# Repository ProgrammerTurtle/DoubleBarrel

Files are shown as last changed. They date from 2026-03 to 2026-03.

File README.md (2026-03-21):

# DoubleBarrel HotEnd

DoubleBarrel is a **high-flow**, **ultra-long-meltzone** 3D printer hotend for my **high performance** custom builds, mainly [Quantumania](https://github.com/ProgrammerTurtle/Quantumania).

With an 80mm meltzone and dual 80mm long mains heater cartridges, totaling a whopping 240 watts, this is a hotend that will heat up in no time and maintain higher flow than *almost* any existing extruder can handle. **Almost**. 

doublebarrelhotendmain

This hot end was designed for HackClub Rework.

BOM can be found here: https://docs.google.com/spreadsheets/d/14wA_01cgvaOd5QHaDqMIIcFyreSTBU4sJwGjdPKG2RY/edit?usp=sharing or attached as a .csv

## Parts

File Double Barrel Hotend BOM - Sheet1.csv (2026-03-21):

Item | Price | Quantity | Source | Useage
CNC Machined Heatblock | $24.53 | 1 | JLCCNC | Hot Side of Hot End
SLM Heat SInk | $13.00 | 1 | IN3DTEC | Cold Side of Hot End
V6 Smooth Heatbreak | $4.00 | 1 | https://www.aliexpress.us/item/3256803198277956.html? | Connect Cold Side to Hot Side
Supervolcano Adapters | $16 | 3 | https://www.aliexpress.us/item/3256805546562989.html? | Meltzone, connect v6 nozzle to heatbreak. Buying multiple as I have to cut them to size to reach my desired length
V6 Nozzle | $3.50 | 1 | https://www.aliexpress.us/item/3256807882929417.html? | Control extrusion resolution. Plastic comes out of here.
Heaters | N/A |  | Self Purchasing | Heat Up Block
Braces | N/A | 2 | Self Purchasing | Brace hot block against heatsink so the heatbreak doesn't snap
M3 Stud Thermistors | $9 | 4 | https://www.aliexpress.us/item/2255800218330851.html? | Monitor Temps, with dual redundancy on each heater
M2x5 Screws | $1.65 | 8 | https://www.aliexpress.us/item/3256802094874740.html? | Assembly
M3x6 Screws | $1.72 | 8 | https://www.aliexpress.us/item/3256802094874740.html? | Mounting/Bracing
Total | $73.40

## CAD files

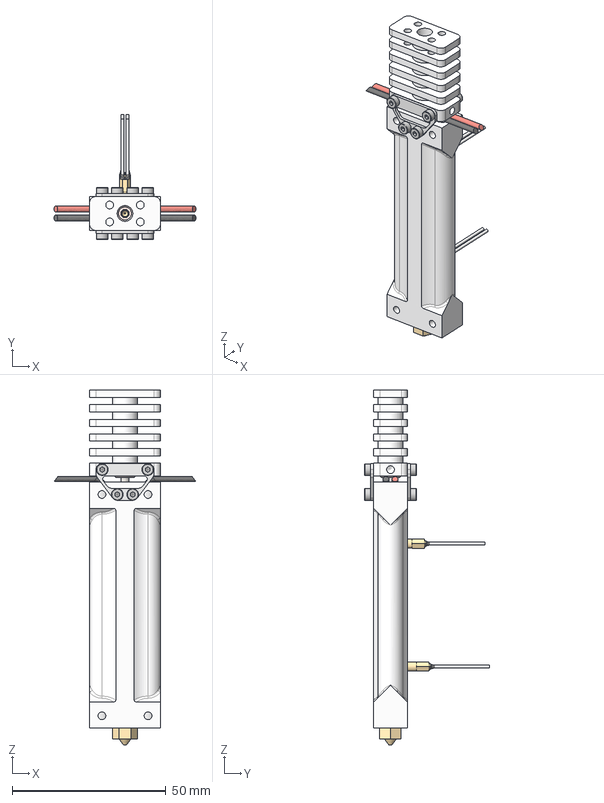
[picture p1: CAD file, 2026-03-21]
CAD/DoubleBarrelHotend.step
46.2 x 40.7 x 115.5 mm
copper hotside
titanium throat
copper coldside
Heatsink
Brace (1)
Brace
V6 0.4mm nozzle
meltzone adapter
dual80mmheater_HotBlock
ISO 4027 - M3 x 3 Steel 4.6 Plain x 4
ISO 4762 - M2 x 5 Steel 4.6 Plain x 8
M3 Stud Thermistor x 2
Heaters

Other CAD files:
CAD/DoubleBarrelHotend.f3z

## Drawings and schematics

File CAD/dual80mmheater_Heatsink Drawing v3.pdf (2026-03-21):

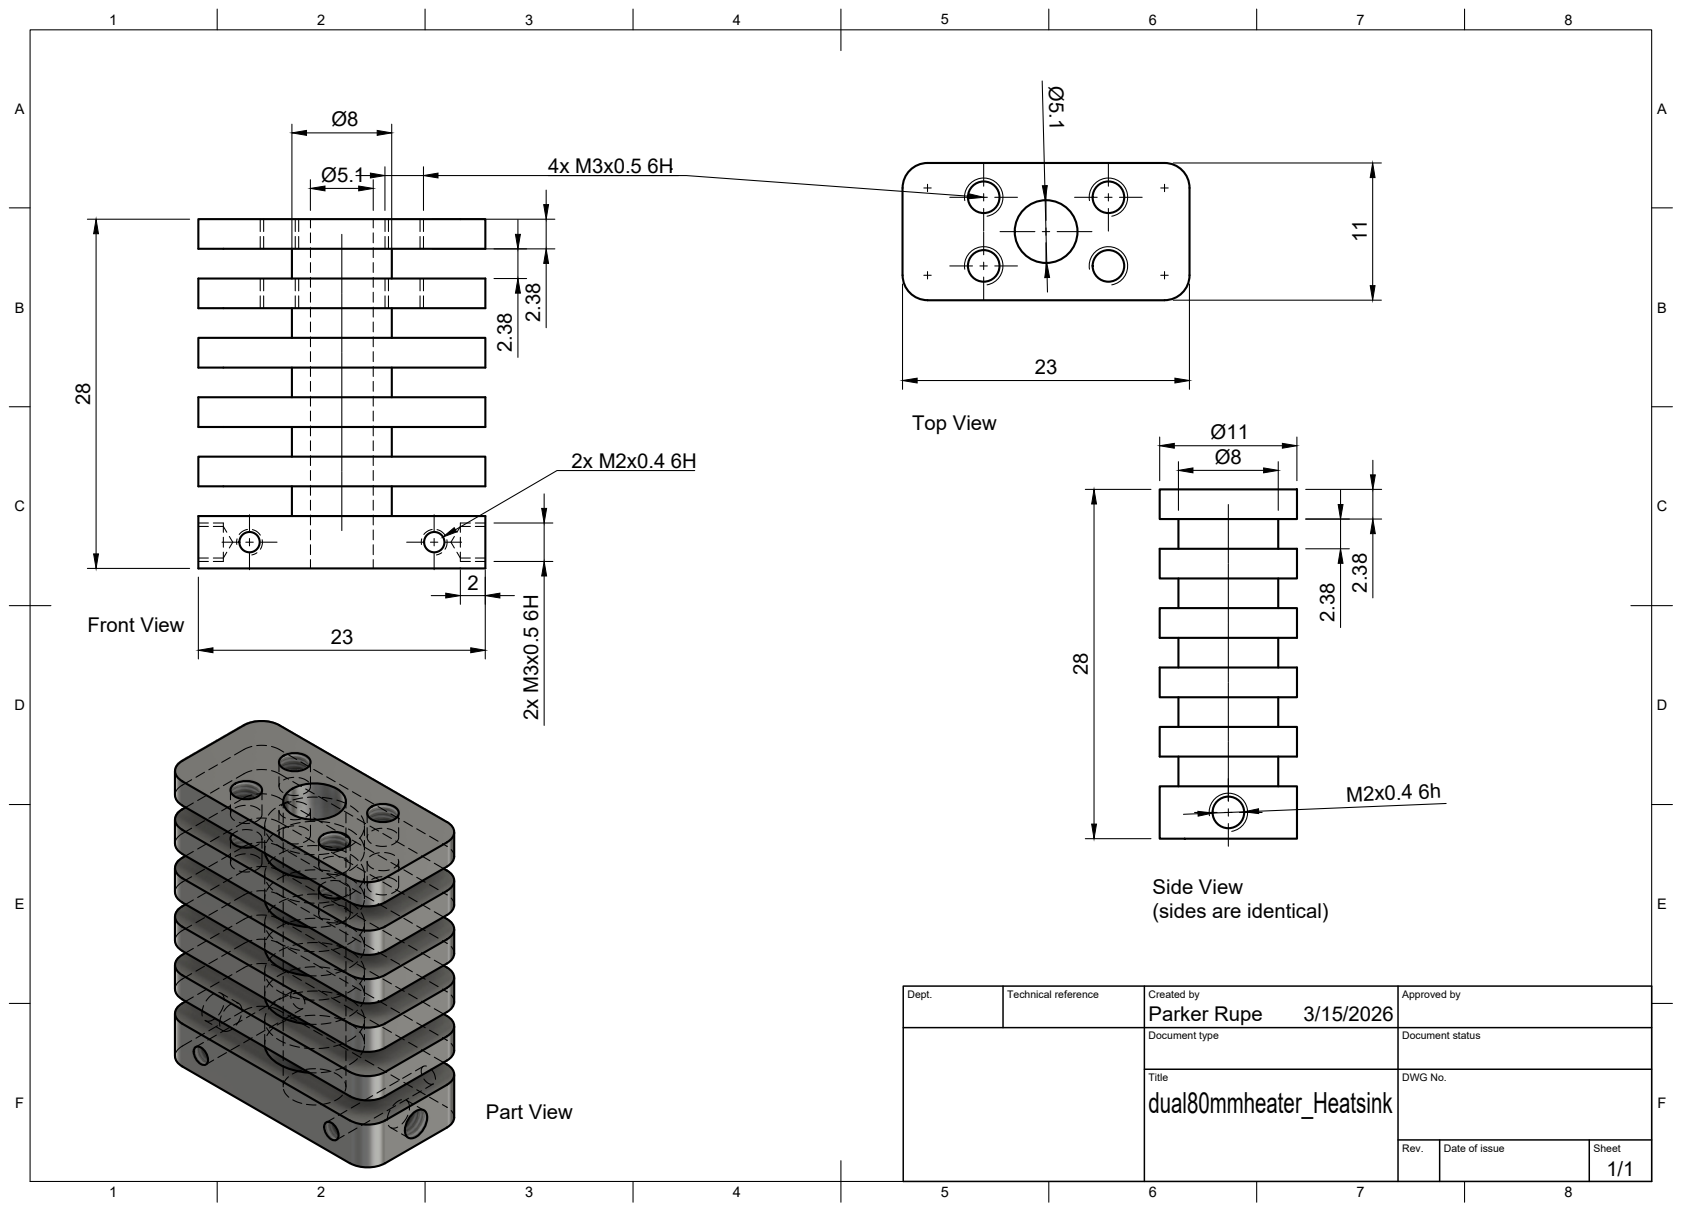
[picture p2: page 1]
Title; DWG No.; Rev.; Date of issue; Sheet; Parker Rupe 28; Top View; Front View; Part View

Side View
(sides are identical)

Dept. | Technical reference | Created by 3/15/2026 | Approved by

Document type | Document status

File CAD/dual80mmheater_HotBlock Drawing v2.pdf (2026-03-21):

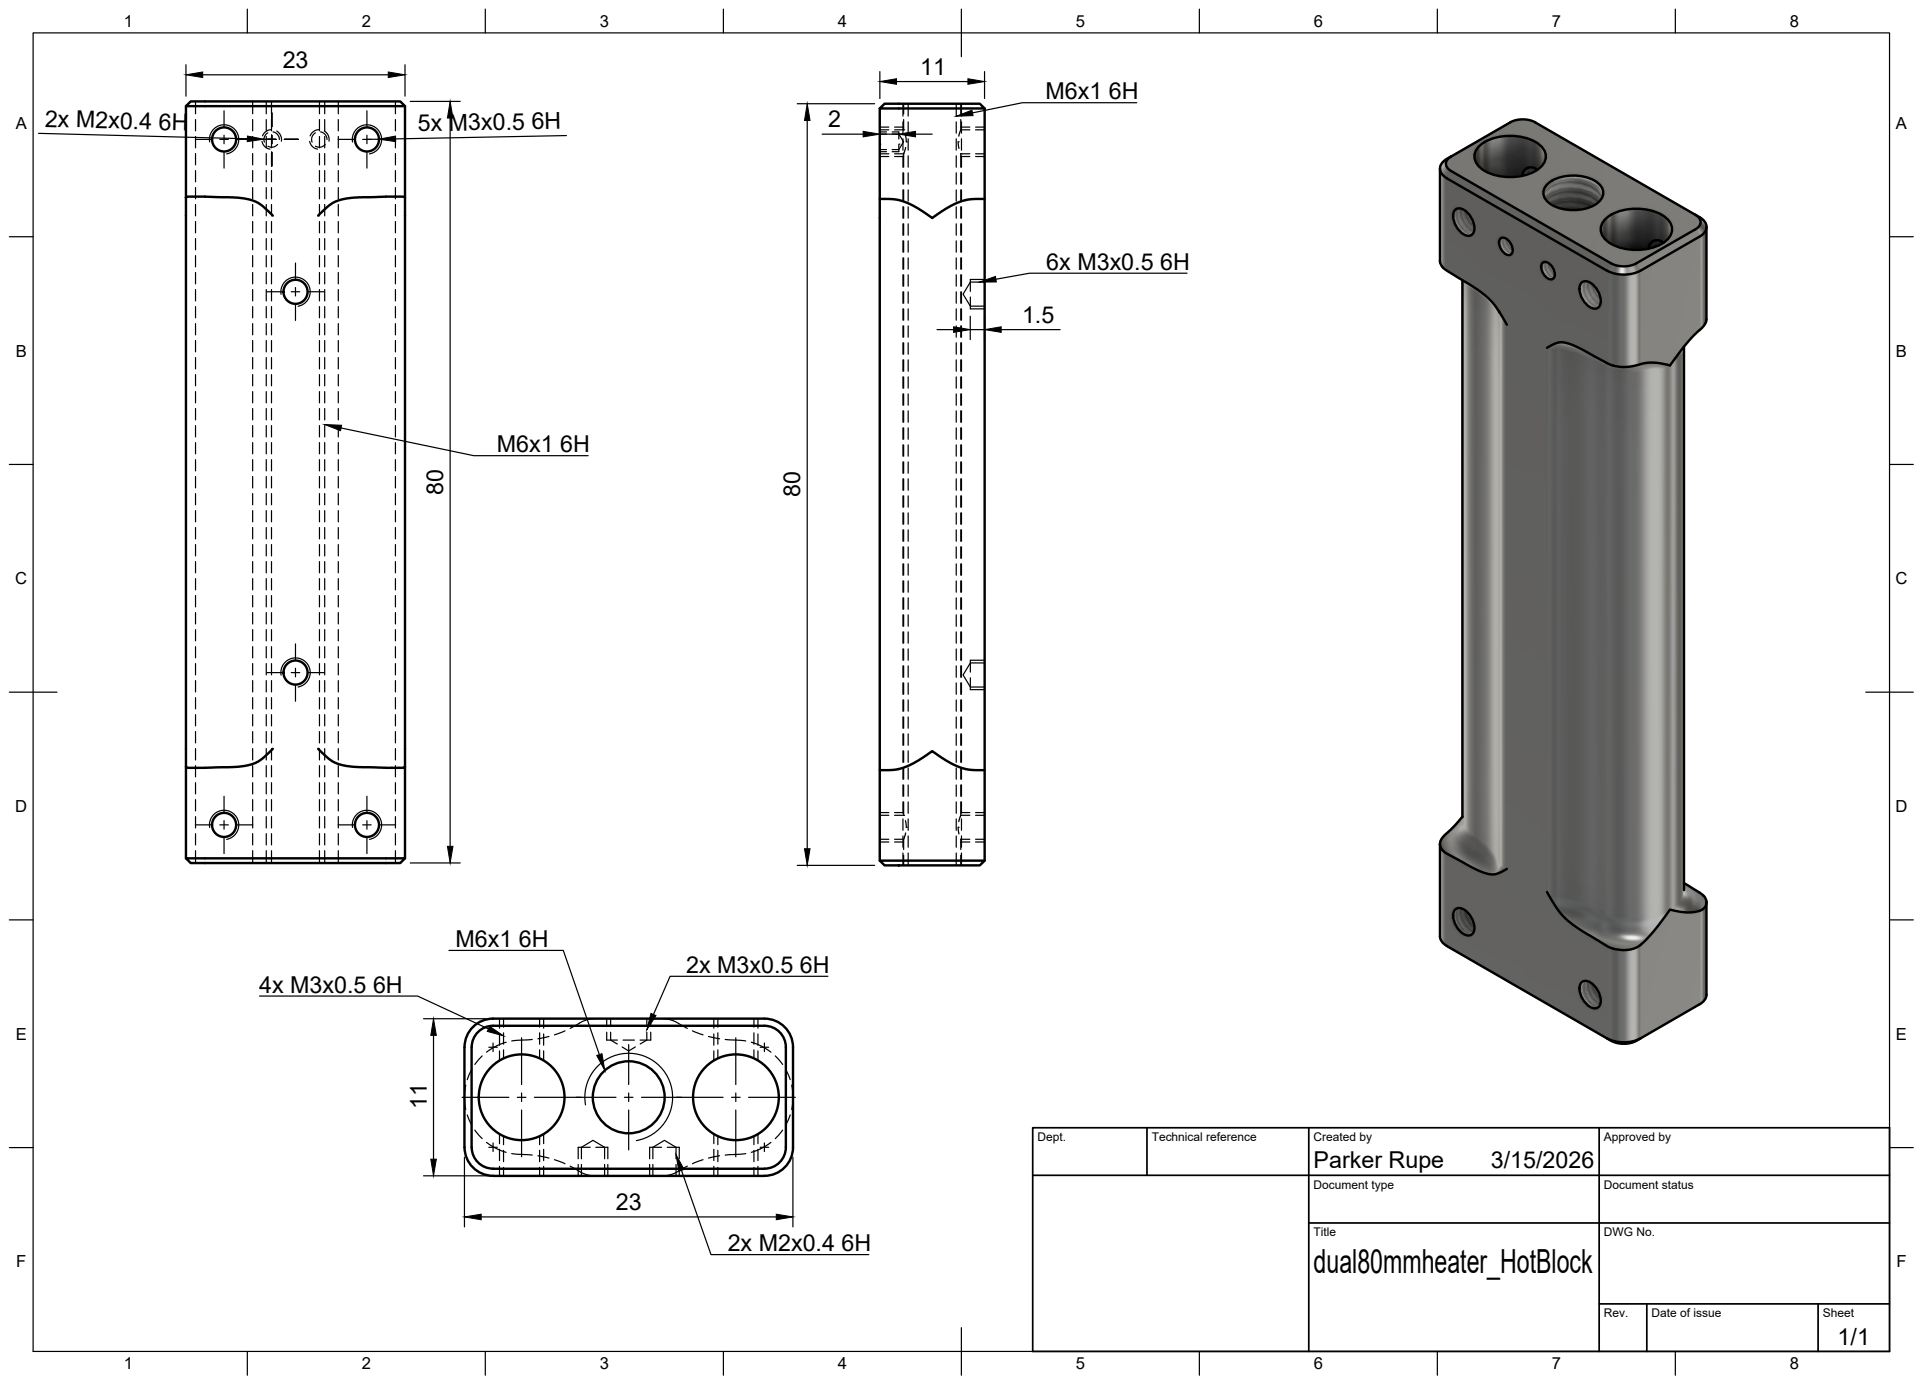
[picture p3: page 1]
Title; DWG No.; Rev.; Date of issue; Sheet

Dept. | Technical reference | Created by Parker Rupe 3/15/2026 | Approved by

Document type | Document status

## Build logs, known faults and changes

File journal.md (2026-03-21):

doublebarrelhotendnobg# Journal of the Design and eventual Build Process of my high-performance custom hotend, Double Barrel. 
### Parker Rupe
### Total Hours: 19.5

## Journal Entry 1: 3/1/2026
Time Spent: 6 Hours

Okay. So, this will be my first custom hotend design that I actually finish, but not my first custom hotend design. I actually started designing one in the past for Quantumania which utilized four supervolcano heaters. However, I have decided I honestly don't really like it. 4 heaters feels like a bit much and keeping it at 24v introduces a lot of nastiness when it comes to breakout boards and whatnot due to absurd amperage. 
So, after a bit of digging on AliExpress (half an hour D:) I found some 6x80mm 120w mains heater cartridges that should be pretty perfect. Of course, I will use two of them, for sillies. I almost used three but I didn't want to copy tricorn or 1Mon's custom hotend. I even considered 4, like the original hotend, but... that would be able to melt a block in literal seconds. In theory two could do that too, but theres no need to go so absurdly overboard.
I actually have a plan for protecting myself in event of mosfet failure that I will detail later. 
https://www.aliexpress.us/item/3256802953795845.html
These are the heaters. For some reason I can't buy less than 10 for cheaper? It is what it is. 
Anyways, I started off by making a quick sketch to outline spacing between the heaters and meltzone. 



It's kind of a mess but it is what it is tbh. Most importantly, it's functional. 
That then gets extruded 80mm, as that is what I want for my hot side length. Match the heaters. 



From there I sketch and extrude a top/bottom so that I have enough material for mounting, heater retaining, etc. 



Next comes fillets and mounting holes. The ones to the side are heater setscrews (on the barrels if you will... double barrel... double heater... anyways). The ones on the center flat part are for M3 stud thermistors. I LOVE M3 thermistors. I use them on everything. So handy. 



That took about an hour and a half as I had to change it a few times to make spacing realistic and whatnot. I also had a lot of issues with the fillets for some reason? Fusion is weird sometimes.

I'm gonna skip ahead about 3-4 hours because going step by step is a really boring read. In order I:
Inserted the heatbreak and nozzle
Designed a basic heat sink
Added heat sink bracing





The heat break is some cheapo mellow one that I was using for my old hot end design - I don't have the link right now but I will add it next entry!. The heatsink is quite simple, copying the fin style/count of the TZ E3 heatsink because I know that configuration works and I am not really space or mounting constrained. I don't really have mounting yet actually but... it will happen.
The braces are 1mm lasercut titanium. Titanium is a really bad heat conductor, and the struts are thin, so it won't conduct much heat at all into the heatsink. It is kinda funny to brace it up here considering the sheer cantilever of mass with the brutal length of the hotend... but I am NOT snapping a heatbreak again. 
All the hardware for this fella will be M3 or M2. M2 on the cold side, M3 on the hot side. Super simple. 



The heat sink was made with a simple projected sketch and pattern. I created a seperate cylindrical core so I didn't have to worry about preserving it for making the fins and then just combined all the bodies (fins and cylinder core) into the one heat sink.
That's all for today. Next I need to work on adding hardware, budget planning, machineability optimization, and part sourcing. 

## Journal Entry 2: 3/8/2026
Time Spent: 4.5 hours

Uhhh. So JLC told me that they won't do a 67mm long 2mm diameter hole in my heatblock. Crazy !! So... I have to figure out a meltzone adapter. Because they can do an M6 hole apparently! 
Spoiler alert... I spent 3 hours searching for options that could work or ways to get one custom made. Ugh. 
First things first I threw together a quick model and drawing of the part I need. The point of the drawing will be clear soon. 



By the way. This drawing is abhorrent. My engineering friend yelled at me when he saw it and said it hurt him. But it gets the point across. 




Basically it is a 67mm (shut up) long M6 threaded rod with a 2mm throughbore and an M2 hex drive on the end. These exist for supervolcano and volcano hotends to allow for normal v6 nozzle useage in long blocks.
This brings us to the first few options. I can adjsut the length of the block slightly (a little shorter or a little longer) to allow for stacking up 2 supervolcano adapters or 1 supervolcano adapter and 3-4 volcano adapters. The first option results in a 100mm ish meltzone... which is literally the max z print height of Quantumania... uhhhhh... Yeah I don't want to do that. The second option is just flat out silly. It would work better, but man is it a lot of possible leak/fail points. And it makes assembly super annoying as you have to heat tighten all 4 or 5 inserts. 
So after researching those available inserts and doing the math for all the combo possibilities... I decided that I don't want to do that. So, I emailed Misumi. 

I have utilized Misumi before for custom linear shafts, for a combat robot weapon assembly. They allow you to customize it in a lot of ways and it is super affordable! But, they don't have a way to do a hex drive, nor fully threaded (it needs like 2mm of not threaded due to configurator weirdness). I decided to see if it could be done through their "fully threaded stud/bolt" item. This got quite close too! But unfortunately, there is not an option for a through bore. So, I sent them an email, with the drawing/sketch from earlier, basically asking if they had a way to do this part that I was missing. I think they do have a way, I just can't find it, despite spending 2 and a half hours on their site. I waited "on hold" with their chat bot for a while before it eventually said support was not active right now and to send an email. It is like 6:30 AM on a sunday but still I wanted to try.
Besides that, I will probably try to quote one from JLC if misumi says they cannot do it or if it is too expensive. Which means I need to actually make a proper drawing and I don't know if they can do hex broaching so this might get some weird drive socket. 

That genuinely took way longer than I thought it would. But that's ok. TL;DR, need to use an M6 threaded meltzone, like Chube, and tried to figure out sourcing a custom one. 

## Journal Entry 3: 3/15/2026
Time Spent: 4 hours

Okay, today was pretty much finishing touches for submission. I added some mounting options and made mechanical drawings so I can request proper quotes from JLCCNC for BOM pricing. 

For mounting, I have both a 4 hole top mounting option and a 2 hole side mounting option. This allows for flexibility in mounting. I don't need to worry a ton about how rigid it is because I need to brace at the bottom of the hotend either way. Not saying these won't be rigid, but it is less of an issue. This took about half an hour as I had to go through my various printers and see what mounting options would fit as I want flexibility and versatility. 

I ended up going with: 



This 4 hole mounting up top, which is a 4 hole M3 5.5 x 10mm pattern. This allows a bowden tube/connector to fit. 



This is the second mounting option, with a matching hole on the opposite side. This is also M3. This option will not be stable without bracing on the end of the hotend. The other option I feel needs end bracing for performance aswell, but technically it is optional. 

As for finishing touches, I just went through and toleranced everything, made my holes have cone ends so they can be drilled properly, etc. 
I also made drawings! Here are those. 



This is the heatsink drawing, which calls out all major dimensions and more importantly threaded holes for the heatsink. A little bit messy but very usable and one of my better drawings. This took an hour and a half. 

 

And this is the heater block drawing. This was a little difficult as it was smoothing out the edges of the center flat section, making the part drawings weird as they lacked those center lines. I made it work though, hopefully JLC likes it. 

That took the remaining 3.5 hours of this session, besides submitting for a quote of course. I hate making drawings and need to practice so that is the main reason why it took a hot minute - I had to do some research on proper procedure for calling out threads and whatnot. 
Once I get the quotes back on Monday, I will submit this project! 

## Journal Entry 4: 3/18/2026
Time Spent: 3 hours

Hi gang. Gonna be a bit more informal with this one because formality gets a bit boring sometimes. 
So, I got the quotes back. 



I submitted them and soon got an email saying there was an issue. I panicked. I thought they wouldn't be able to machine my heaterblock because of the stupid 80mm long M6 tapped hole. But! The issue was just something with shipping. After I fixed that it actually passed review with no errors. I am amazed. 
It's a bit expensive though, especially the heatsink, which costs more than the heaterblock somehow. This means I will have to resort to getting the heatsink SLM'd by In3DTec out of aluminum. I also made some changes to the heaterblock that I will show here, but basicallly I just nuked the fillets to save money. I also figured out what I will do for the melt zone adapter - I will be buying two supervolcano adapters and cutting one down to size. 



Here's the mew block. Much simpler but still retains the look I was going for. I actually like the chamfers more than the fillets. I had to make some changes to the mechanical drawing aswell to account for the new model and highlight the absurd 80mm long M6 tapped hole, but those changes are not super large so I don't think I will put screenshots. But, they will be uploaded to the repo. 



That makes this the hotend now, minus screws. Looks pretty cool! 
Once JLC responds to my new quote, which should happen tonight, I can actually submit this thing. In the meantime, I started finding aliexpress stuff for my BOM. We have: 
Heaters: https://www.aliexpress.us/item/3256802953795845.html
Supervolcano Adapters: https://www.aliexpress.us/item/3256805546562989.html



This is the In3DTec quote for the heatsink, which is a great price. I just have to tap it myself because I don't want to deal with their tapping stuff, but thats fine.

I also need to get quotes for the heatbreak braces. I plan on getting them made by JLC out of 1mm stainless steel, as steel is a poor thermal conductor (and a dissimilar metal from aluminum which helps even more). I have to wait until midnight GMT+8 (10am my time) to submit that quote though as they are running the sheet metal service at very low capacity, and today's capacity is full. 

That's basically it. Optimizing stuff for the correct prices and adjusting my drawings to account for the manufacturability changes took a while. Fusion is also a bit goofy when it comes to chamfers/fillets so I had to deal with that. 
With any luck, I can submit tomorrow. 

## Journal Entry 5: 3/19/2026
Time Spent: 2 hours

Okay, I missed the window to quote the braces. Whoops. I will try again tomorrow. As for today, I put the finishing touches on the 3D model, wrote most of the BOM, and worked on formatting my repo. 

I basically just added all the hardware and made colors/materials correct. I modeled M3 stud thermistors and the 80mm heaters myself. 



Here is everything new 



And finally, here are the renders ! I spent about 10 minutes color matching things and adjusting lighting. 

Double Barrel Hotend

doublebarrelhotendnobg

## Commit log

2026-03-08 Add journal entry for custom hotend design process
    Document the design and build process of a custom hotend, detailing initial sketches, heater selection, and component design.
2026-03-15 Document final touches and drawings for submission
    Added Journal Entry 3 detailing final touches for submission, including mounting options and mechanical drawings for quotes.
